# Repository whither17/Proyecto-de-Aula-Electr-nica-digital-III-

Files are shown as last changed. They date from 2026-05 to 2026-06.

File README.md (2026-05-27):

## Descripción detallada del proyecto final 
*Black Sisyphus*

Proyecto final del curso <br>
**Electrónica Digital III** 

Integrantes equipo Turing

**_Andres Felipe Agudelo Zapata_**<br>
**_Robinson Correa Morales_** 

---

## Descripción

El proyecto consiste en un robot autónomo capaz de:

- Navegar dentro de una región delimitada.
- Detectar cajas mediante sensores.
- Clasificar cajas negras y blancas.
- Expulsar únicamente las cajas negras del área de trabajo.
- Ignorar las cajas blancas.
- Generar un mapa virtual del entorno.
- Reexplorar el área periódicamente.

La arena de pruebas tiene dimensiones aproximadas de **100 cm x 70 cm** y está dividida en 4 cuadrantes mediante líneas negras de cinta aislante.

---

# Hardware utilizado

## Procesamiento
- Raspberry Pi Pico

## Sensores
- MPU-6050 (IMU)
- HC-SR04 (Ultrasónico)
- Sensores infrarrojos
- Encoders integrados en los motores N20

## Actuadores
- 2 Motores N20 con encoder
- Driver TB6612FNG

## Alimentación
- Batería Li-Po 7.4V
- Reductor MP1584

---

# Características

- Navegación autónoma
- Odometría y fusión sensorial
- Control PID
- Detección de límites
- Clasificación por color
- Mapeo periódico del entorno

---

# Arquitectura de software

El firmware utiliza una arquitectura basada en Polling + Interrupciones.

## Capas del sistema

### Drivers
Control e integración de hardware:
- TB6612FNG
- IMU
- Ultrasonido
- Encoders
- Sensores infrarrojos

### Estimación
- Odometría
- Fusión sensorial
- Estimación de posición
- Generación del mapa virtual

### Navegación y control
- Control PID
- Planeación de trayectorias
- Corrección de movimiento

### Aplicación
Implementa la lógica general del robot mediante una máquina de estados.

---

# Máquina de estados

| Estado | Función |
|---|---|
| APP_INIT | Inicialización |
| APP_EXPLORE | Exploración |
| APP_APPROACH_BOX | Aproximación a cajas |
| APP_IDENTIFY_BOX | Identificación del color |
| APP_PUSH_BOX | Expulsión de cajas negras |
| APP_CENTER | Retorno al centro |
| APP_WAIT | Espera para nuevo mapeo |

---

# Requisitos funcionales

- Navegación autónoma.
- Exploración sistemática.
- Detección de cajas.
- Clasificación por color.
- Expulsión de cajas negras.
- Ignorar cajas blancas.
- Retorno automático al centro.
- Reexploración periódica.

---

# Requisitos no funcionales

- Peso menor a 1 kg.
- Fácil transporte.
- Estructura resistente.
- Autonomía mínima de 15 minutos.
- Bajo consumo energético en espera.

---

# Pruebas

1. Detectar y expulsar una caja negra.
2. Detectar e ignorar una caja blanca.
3. Clasificar múltiples cajas negras y blancas.
4. Retornar al centro al finalizar.
5. Reiniciar el mapeo automáticamente.

---

# Estructura del proyecto

```text
├── Drivers
│   ├── Driver_TB6612FNG
│   ├── imu
│   ├── ultrasonic
│   ├── encoder
│   └── infrarrojo
│
├── Estimacion
│   └── estimacion.c/h
│
├── Navegacion
│   ├── control.c/h
│   └── navegacion.c/h
│
└── Aplicacion
    └── aplicacion.c/h

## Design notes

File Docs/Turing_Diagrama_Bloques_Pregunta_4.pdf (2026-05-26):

ROBINSON CORREA MORALES | AVANCE DEL PROYECTO FINAL
ANDRES FELIPE AGUDELO ZAPATA | 23/05/2026
ELECTRÓNICA DIGITAL III

### Diagrama de Bloques

La alimentación del circuito es mediante una batería Li-Po con voltaje nominal de 7.4 V que después cae a un reductor de voltaje MP1584 que la reduce a 5 V. Con este voltaje se alimentan tanto el pin VSYS de la Raspberry Pi pico como el sensor de ultrasonido. Por su parte, el pin de VM del puente H TB6612FNG es alimentado con los 7.4 V suministrados por la batería.

Para el puente H además de la conexión de los 7.4 V con su respectiva tierra se conectan los pines de VCC, STDBY a el pin de 3.3 V y se pone la tierra común del pin de la Raspberry, además los pines de AI1, AI2, PWMA, BI1, BI2, PWMB se conectan a los GPIOS de la Raspberry mientras que los pines de A01, A02, B01, BO2 se conectan a los cables rojos y blancos de los dos motores N20.

Para hacer uso de los encoders acoplados a los motores alimentamos los cables negros a 3.3 V y los azules a GND y las salidas de los dos canales cable amarillo y verde van a 2 pines GPIOs.

Ambos sensores infrarrojos se alimentan a 3.3 V que los proporciona la Raspberry y sus salidas se leen en GPIOs.

La IMU también se alimentan a 3.3V y se conectan los pines SDA y SCL a dos pines de la Raspberry que soporten comunicación I2C.

El ultrasonido es el único sensor que no se debe alimentar a 3.3V, ya que trabaja a 5 V, para proteger la Raspberry, salida de este sensor(el pin Echo) debe pasar por un divisor de tensión con resistencias de 4.7k y de 10k. La entrada (Trig) puede funcionar con una entrada de 3.3 V por lo que no requiere acondicionamiento.

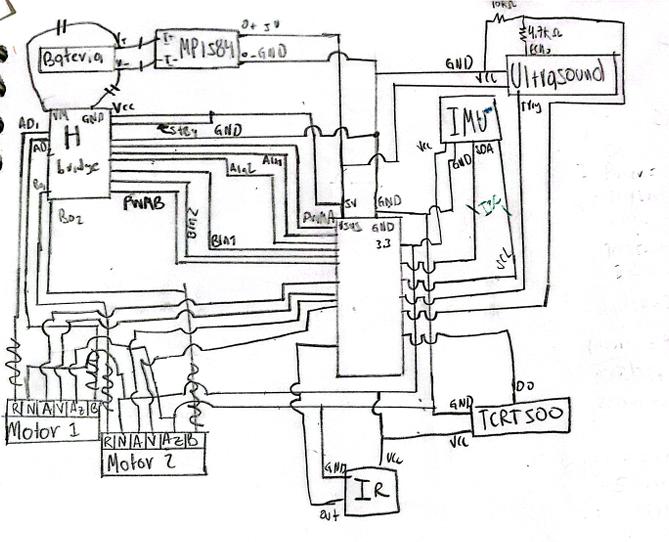
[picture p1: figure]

ROBINSON CORREA MORALES | AVANCE DEL PROYECTO FINAL
ANDRES FELIPE AGUDELO ZAPATA | 23/05/2026
ELECTRÓNICA DIGITAL III

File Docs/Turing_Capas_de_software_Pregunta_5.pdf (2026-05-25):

ROBINSON CORREA MORALES | AVANCE DEL PROYECTO FINAL
ANDRES FELIPE AGUDELO ZAPATA | 23/05/2026
ELECTRÓNICA DIGITAL III

### Respuesta a la pregunta 5

Arquitectura de software
El firmware del sistema estará organizado mediante una arquitectura de Polling más interrupciones. Las interrupciones se utilizan en puntos críticos donde se requiere minimizar el error. Dado que el robot debe navegar por si mismo, saber dónde está y corregir su movimiento, evitar que el error se acumule es crucial. El software está conformado por las siguientes capas:
- Drivers
- Estimación
- Navegación y control
- Aplicación

Drivers
Esta capa se encarga de configurar e inicializar los diferentes sensores y sistemas del vehículo y ofrecer una integración transparente entre el hardware y el resto del software. Aquí se incluyen los drivers de ambos motores, el driver de la unidad de medición inercial, el driver del sensor ultrasónico, driver del encoder de los motores y el driver de los sensores infrarrojos detectores de línea. La capa Drivers está conformada por los siguientes módulos:
- | Driver_TB6612FNG: | Conformado | por | los | archivos | Driver_TB6612FNG. | c /
Driver_TB6612FNG.h | , implementa las funciones que permiten realizar las siguientes tareas:
- Implementar las funciones de control de velocidad.
- Dirección del giro del motor.
- Generación del PWM necesario para controlar la velocidad.
| • Frenar el motor.
- | IMU: Conformado por los archivos imu.c / imu.h | , implementa las funciones que permiten
configurar, inicializar y utilizar la unidad de medición inercial (IMU). Las tareas de este módulo
| son:
- Inicializar la comunicación I2C
- Configurar los registros internos del MPU-6050.
- Realizar calibración.
- Leer los datos crudos medidos por el acelerómetro y giroscopio.
- Establecer los rangos de las mediciones.
- Procesar las mediciones y transformarlas en unidades físicas utilizables por el sistema.
- | Ultrasonic: Conformado por los archivos ultrasonic | .c / | ultrasonic | .h , implementa
las funciones que permiten utilizar el sensor ultrasónico HC-SR04. Sus tareas son:
- Gestionar la temporización del sensor ultrasónico.
- Generar los pulsos de disparo del sensor.
- Medir la duración del eco.
- Estimar de la distancia.

ELECTRÓNICA DIGITAL III

Este módulo emplea interrupciones de temporizador (TIMER_IRQ) para medir con precisión la duración de los pulsos y estimar correctamente la distancia.

- | Encoder: Conformado por los archivos encoder.c /encoder.h | , se encarga de determinar
las revoluciones y el recorrido de cada rueda. Sus tareas son:
- Contar los pulsos por medio de las interrupciones GPIO
- Implementar una temporización periódica para el cálculo de velocidad angular.
- Estimar las RPM del motor.
- Estimar el desplazamiento del robot.
- Filtrar las lecturas de ser necesario.
- | Infrarrojo: Conformada por los archivos infrarrojo.c / infrarrojo.h | , permite
ejecutar las tareas relacionadas con la lectura de los cuadrantes del área de trabajo y el límite de esta además de identificar el color de la caja. Dado que el robot posee dos sensores infrarrojos con tareas distintas, se aclara que cada sensor tiene sus funcionalidades específicas:
- Sensor inferior: Detectar los límites del área de trabajo.
- Sensor frontal: Determinar el color de la caja cuando el robot se acerque a ella.

La información de estos sensores les indica a las capas superiores información relevante para la corrección del mapa del entorno.

Estimación
Esta capa se encarga de realizar la odometría y la fusión sensorial. Se comunica con la capa de drivers, de donde obtiene los datos necesarios para saber en donde se encuentra el robot. Esta capa le da la capacidad al robot de responder a las preguntas ¿Dónde estoy? ¿Qué hay en el entorno? ¿Cómo me estoy moviendo? Por medio de la integración de las distintas métricas. Esta capa es un único módulo formado por los archivos
estimaci | on.c / estimaci | on.h , Las funciones del módulo son las siguientes:
- Realizar la odometría del robot
- Obtener los datos de la unidad de medición inercial.
- Fusionar los datos de la IMU con la odometría reduciendo el efecto de deriva.
- Detectar las cajas por medio de la lectura del sensor ultrasónico.
- Determinar el color de la caja.
- Estimar la posición del robot en el área de trabajo tanto en (x, y) como angularmente.
- Estimar la velocidad del robot.
- Determinar la distancia a la caja.
- Generar el mapa virtual del entorno.

Navegación y control
Esta capa se encarga de controlar el movimiento del robot y planificar su trayectoria por medio de distintas métricas proporcionadas por la capa de Estimación. Esta capa la conforman dos módulos control.c /.h y navegaci on.c/.h
- Control: Sus funciones son:
- Realizar el control de bajo nivel de la velocidad y dirección del motor.
- Implementar el control PID de los motores.

ELECTRÓNICA DIGITAL III

- Corregir las desviaciones en la trayectoria.
- Navegación: Sus funciones son:
- Calcular la ruta hacia las cajas detectadas.
- Ignorar las cajas que ya han sido identificadas por su color.
- Coordinar las maniobras de aproximación y empuje.
- Detectar la salida del área de trabajo y corregir la ruta para reingresar a él.
- Generar referencias de orientación y velocidad para el robot.

Aplicación
Esta capa integra la aplicación del robot. Define el comportamiento específico a nivel de usuario, dictando que hace y que no hace el robot. El robot busca cajas dentro de su entorno de trabajo y extrae de él las cajas de color negro e ignora las cajas de otro color. Cuando detecta a distancia una caja, si no la ha identificado antes, se acerca a ella y la identifica. Si la caja identificada es negra, la expulsa fuera del área de trabajo. Una vez no hallan más cajas negras, el robot se situará en el centro del área de trabajo y volverá
a leer el entorno pasados 4 minutos. Está conformada por el módulo aplicación.c/.h | , cuyas funciones
son:
- Tomar las decisiones de alto nivel por medio de la máquina de estados general del robot.
- Coordinar las capas inferiores.
- Implementar el comportamiento general del robot cumpliendo así con los requisitos funcionales propuestos.

La Máquina de estados tiene por estados:

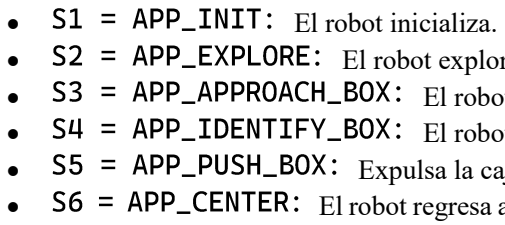
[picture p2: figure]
APP_INIT : El robot inicializa.

- | S2 = | APP_EXPLORE : El robot explora su entorno y crea un mapa virtual de él.
- | S3 = | APP_APPROACH_BOX : El robot busca cajas en la distancia y las detecta.
- | S4 = | APP_IDENTIFY_BOX | : El robot identifica la caja que tiene en frente.
- | S5 = | APP_PUSH_BOX : Expulsa la caja identificada si es de color negro.
- S6 = APP_CENTER : El robot regresa al centro del área de trabajo cuando ya no queden cajas
| negras.
- | S7 = | APP_WAI T: El robot espera durante un tiempo definido para volver a explorar.

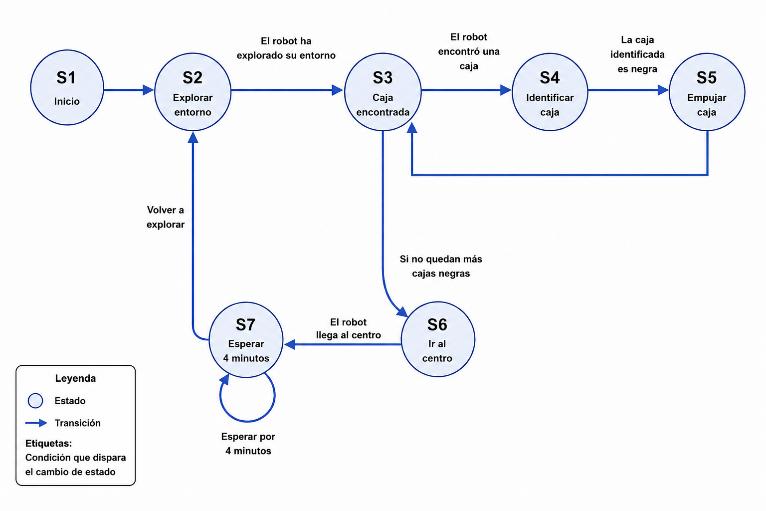
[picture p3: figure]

Esquema de la máquina de estados finitos de la aplicación.

ELECTRÓNICA DIGITAL III

Dado que el sistema posee una arquitectura basada en Polling + Interrupciones, las interrupciones son empleadas en aquellos puntos críticos donde se requiere reacción rápida por parte del sistema. Las interrupciones más importantes utilizadas son:

Interrupciones GPIO
Empleadas por los encoders de los motores, se utilizan para detectar los flancos de pulso. Cada interrupción incrementa o decrementa el conteo de los pulsos necesarios para la odometría. También es utilizado por el driver del sensor infrarrojo.

Interrupciones de TIMING
Empleadas principalmente por el sensor ultrasónico para medir correctamente la distancia y por el módulo Driver_TB6612FNG para realizar el envío periódico de la velocidad y dirección. También se utilizarán interrupciones de timing e interrupciones periódicas en secciones de la lógica que requieran manejo del tiempo.

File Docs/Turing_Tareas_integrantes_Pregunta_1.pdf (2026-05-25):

ROBINSON CORREA MORALES | AVANCE DEL PROYECTO FINAL
ANDRES FELIPE AGUDELO ZAPATA | 23/05/2026
ELECTRÓNICA DIGITAL III

### Tareas integrantes

Andres Agudelo:

- Montaje del chasis. (80%):
Búsqueda del diseño 3D del carro su acople y verificación de su correcto funcionamiento
- Diseño de la PCB. (100%)
Diseño del shield de la raspberry pi pico con acondicionamiento de señales en los GPIOS que lo requieran.
- Compra de materiales. (99%)
- Testeo de componentes. (60%)
Verificación de que todos los componentes comprados funcionen adecuadamente y estén listos para su uso en el proyecto.
- Desarrollo de la odometria. (10%)
Desarrollo de la odometria del carro por medio de los enconders, el uso de la IMU y la corrección de errores acumulativos por medio de las líneas en los bordes y la cruz central que divide la arena en 4 cuadrantes.
- Desarrollo del mapa de obstáculos en la memoria. (0%)
En base a la posición del carro su orientación y la información que brinde el sensor de ultrasonido definir un mapa de obstáculos.
- Desarrollo del control del carro. (0%)
Desarrollo del movimiento de mapeo de la región del carro evitando los obstáculos que se encuentren en la región.
- Desarrollo de la arquitectura de Hardware. (100%)

Robinson Correa:

- Impresión PCB. (100%)
- Desarrollo de comunicación I2C necesaria para el uso de la IMU. (50%)
Para utilizar adecuadamente la IMU es necesario el desarrollo de un protocolo de comunicación I2C para la adquisición de los parámetros del giroscopio y del acelerómetro.
- Desarrollo de la función de empuje de obstáculos. (0%)
Una vez el carro detecte un obstáculo negro el carro deberá de sacarlo de la región de trabajo.
- Desarrollo de la región de pruebas. (100%)
En un pliego de cartulina se desarrolló una región de pruebas con cinta negra en los bordes y una cruz en el centro con cinta negra que divide la región de pruebas en 4 cuadrantes.
- Testeo de la odometria y navegación del carro. (0%)
Realizar varias pruebas en las que se verifique si el carro si logra detectar su posición espacial en cada tiempo y sabe cómo llegar a puntos ya conocidos previamente sin caer en errores.
- Desarrollo del control del carro. (0%)
Mediante revisión de parámetros de control lograr que el carro llegue a las posiciones necesarias sin oscilaciones y en un tiempo adecuado.
- Desarrollo de la arquitectura de Software. (100%)

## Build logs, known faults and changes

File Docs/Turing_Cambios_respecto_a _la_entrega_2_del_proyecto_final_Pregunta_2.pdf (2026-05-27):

ROBINSON CORREA MORALES | Corrección a la entrega número 2
ANDRES FELIPE AGUDELO ZAPATA | 23/05/2026
ELECTRÓNICA DIGITAL III

### Cambios respecto a la entrega 2 del proyecto final

Para el proyecto final se desarrollará un vehículo autónomo, que navegara en una región del tamaño de un pliego de cartulina blanca (100cm x 70cm), dentro de esta región se encontraran dos tipos de cajas unas de color negro y otras de color blanco, el trabajo del robot será sacar las cajas negras de la región, e ignorar las cajas blancas. Una vez no haya más cajas negras en la región el robot volverá al centro y hará nuevos mapeos de la región de manera periódica cada 4 minutos.

El robot se mueve mediante el uso de dos motores N20 (antes: Tracción 4 x 4) que se encuentran en dos esquinas contrarias del chasis, este robot se desplazara mediante el uso de orugas.

Para determinar su posición en el espacio el robot recibe información del mundo exterior mediante 3 sensores, los enconder de cada motor que le dicen cuántas vueltas a dado cada motor, una IMU que nos dará información sobre giros y la orientación del carro y un sensor de línea que detectara las líneas que se encuentran en los bordes de la región y en una cruz que divide la región en 4 cuadrantes iguales (antes: No quedó clara la función del sensor seguidor de línea y las marcas con cinta negra) esta medida la hacemos para actualizar la información de la ubicación del carro con medidas ya conocidas que nos permitirá reducir el error acumulativo que tendría la odometría en caso de no realizarse.

Los principales cambios respecto a la entrega anterior es que se cambió el objetivo de llevar las cajas al centro a simplemente sacarlas del área de trabajo, lo que elimina el estado de espera en la que el carro esperaba que le quitaran la caja del centro, en vez de eso se desarrolló un mapeo periódico de 4 minutos en la que el carro recorrerá de nuevo la región. Las cajas también se han cambiado de un cubo de 4 cm de lado a un cubo de 7 cm de lado, pero mantienen la naturaleza de ser blancas o negras.

También se amplió la región de trabajo de una de 60cm x 60cm a una de 100cm x 70cm de cartulina blanca con bordes y división en 4 cuadrantes señalizados con cinta negra (antes: se daba a entender que era en la cerámica del suelo), lo que tiene más sentido con las dimensiones del automóvil, y se cambió el hecho de que el carro siga una tracción 4x4 por una de orugas como la de un tanque. En base a los cambios las nuevas pruebas serán:

- Prueba 1: Se colocará una sola caja negra en la arena se verificará que el robot la encuentre y la clasifique como negra, para después sacarla de la arena.
- Prueba 2: Se colocará una sola caja blanca se verificará que el robot la encuentre la clasifique como blanca y siga su escaneo de la región ignorando esta caja identificada.
- Prueba 3: Se colocarán 2 cajas negras y 2 blancas en la región de trabajo garantizando que ninguna caja impida el acceso a las demás cajas ni su correcta eliminación hacia uno de los costados la prueba será exitosa cuando en la arena solo queden las 2 cajas blancas.
- Prueba 4: Cuando no haya más cajas negras en el campo de trabajo se verificará que el robot retorne a la región central.

ELECTRÓNICA DIGITAL III

- Prueba 5: Pasados una cantidad de tiempo N el cual por cuestiones de velocidad tomará un valor de un minuto después de que el carro haya retornado a la región central el carro deberá de volver a iniciar un mapeo de la región.

Requisitos funcionales:

- RF1 Navegación automática por odometría y fusión de sensores: el vehículo deberá estimar su posición y orientación en todo momento de su ejecución utilizando los encoders de cada motor, la unidad de medición inercial, el sensor ultrasónico y los sensores infrarrojos seguidores de línea .
- RF2 El vehículo deberá de moverse en la región de trabajo (antes: 60 x 60 cm) de manera sistemática para encontrar todas las cajas en la región.
- RF3 El vehículo deberá de detectar la presencia y ubicación de las cajas por medio de un sensor ultrasónico.
- RF4 Al aproximarse a una caja detectada el robot deberá determinar su color por medio de un sensor de línea infrarrojo.
- RF5 El vehículo deberá de empujar las cajas detectadas como negras fuera de la región de trabajo (antes: Hacia el centro del área de trabajo).
- RF6 Las cajas blancas deberán de ser ignoradas por el robot. Una caja identificada como blanca no deberá ser movida por el robot .
- RF7 El sistema deberá de almacenar internamente las posiciones estimadas de todas las cajas detectadas durante su barrido de la región.
- Requisito eliminado: Una vez se haya llevado una caja al centro de la región el vehículo deberá detenerse y permanecer en espera hasta que esta se retire.
- Requisito eliminado: El vehículo deberá de ser capaz de detectar cuando la caja del centro ha sido retirada.
- RF8 Cuando no haya más cajas negras el robot debe de volver al centro y esperar el tiempo definido para luego volver a mapear su entorno.
- RF9 El robot no deberá salirse del área de pruebas. En caso de que ocurra, deberá reingresar a ella, si no puede, deberá detenerse.

Requisitos NO funcionales:

- Eliminado: El vehículo tendrá tracción 4 x 4 y el cambio de dirección se realizará cambiando la velocidad y sentido cada rueda.
- RNF1 El vehículo será ligero, no superará el kilogramo de peso y será fácil de transportar.
- RNF2 El vehículo estará bien ensamblado, evitando que se rompa al transportarlo o manipularlo.
- RNF3 Las baterías han de garantizar el funcionamiento en todas las pruebas ejecutadas o una demostración de funcionamiento superior a los 15 minutos.

ELECTRÓNICA DIGITAL III

- RNF4 El robot reducirá su consumo energético durante el tiempo de espera tras finalizada una ronda.

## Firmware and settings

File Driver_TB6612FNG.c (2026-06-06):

#include "Driver_TB6612FNG.h"

/* ─────────────────────────────────────────────────────────────────────────────
   DEFINICIÓN DE PINES Y CONSTANTES
   ───────────────────────────────────────────────────────────────────────────── */

/* Motor izquierdo — canal A */
#define PIN_AIN1   20  /* GP20 — dirección izquierdo bit-0 */
#define PIN_AIN2   21  /* GP21 — dirección izquierdo bit-1 */
#define PIN_PWMA   12  /* GP12 — PWM slice 6, canal A      */

/* Motor derecho — canal B */
#define PIN_BIN1   19  /* GP19 — dirección derecho bit-0   */
#define PIN_BIN2   18  /* GP18 — dirección derecho bit-1   */
#define PIN_PWMB   13  /* GP13 — PWM slice 6, canal B     */

/* CONSTANTES */
#define MAXPWM 70 /* Los motores solo reciben hasta 6v la alimentacion es de 7.4v con valores de hasta 8.4v usamos un 70% como segurridad*/
#define PWM_WRAP 12499 /* Para una frecuencia de 10 KHz con reloj del micro de 125 MHz*/
#define PWMSlice 6 /* El canal de PWM a usar es el 6 ya que este es el del GPIO 12(A) y del GPIO 13(B) */

/* ─────────────────────────────────────────────────────────────────────────────
   Variables Internas
   ───────────────────────────────────────────────────────────────────────────── */

/* Ciclos de dureza a aplicar en los motores en la proxima IRQ */
static volatile uint16_t g_duty_left  = 0;
static volatile uint16_t g_duty_right = 0;

/* Banderea de cambio de estado */
static volatile bool g_cmd_pending = false;

/* Base de tiempo por medio del uso de las interrupciones */
static volatile uint32_t g_pwm_ticks = 0;


/* Handler de la interrupcion*/
static void pwm_wrap_isr(void) {
    /* Limpiamos la Flag */
    pwm_clear_irq(PWMSlice);
    g_pwm_ticks++;

    /* Aplicar nuevo duty cycle si hay un comando pendiente */
    if (g_cmd_pending) {
        uint16_t limit =((uint16_t)((MAXPWM * (int)PWM_WRAP) / 100));
        if (g_duty_left > limit)
        {
            pwm_set_chan_level(PWMSlice,  PWM_CHAN_A, limit);
        }else{
            pwm_set_chan_level(PWMSlice,  PWM_CHAN_A, g_duty_left);
        }
        if (g_duty_right > limit)
        {
            pwm_set_chan_level(PWMSlice,  PWM_CHAN_B, limit);
        }else{
            pwm_set_chan_level(PWMSlice,  PWM_CHAN_B, g_duty_right);
        }
        g_cmd_pending = false;
    }
}

/**
 * set_motor_direction_left()
 * Configura AIN1/AIN2 según el signo de speed.
 *
 *   speed > 0  →  AIN1=1, AIN2=0  (adelante)
 *   speed < 0  →  AIN1=0, AIN2=1  (atrás)
 *   speed = 0  →  AIN1=0, AIN2=0  (freno)
 */
static inline void set_motor_direction_left(int speed) {
    if (speed > 0) {
        gpio_put(PIN_AIN1, 1);
        gpio_put(PIN_AIN2, 0);
    } else if (speed < 0) {
        gpio_put(PIN_AIN1, 0);
        gpio_put(PIN_AIN2, 1);
    } else {
        gpio_put(PIN_AIN1, 0);
        gpio_put(PIN_AIN2, 0);
    }
}

/**
 * set_motor_direction_right()
  * Configura BIN1/BIN2 según el signo de speed.
 *
 *   speed > 0  →  BIN1=1, BIN2=0  (adelante)
 *   speed < 0  →  BIN1=0, BIN2=1  (atrás)
 *   speed = 0  →  BIN1=0, BIN2=0  (freno)
 */
static inline void set_motor_direction_right(int speed) {
    if (speed > 0) {
        gpio_put(PIN_BIN1, 1);
        gpio_put(PIN_BIN2, 0);
    } else if (speed < 0) {
        gpio_put(PIN_BIN1, 0);
        gpio_put(PIN_BIN2, 1);
    } else {
        gpio_put(PIN_BIN1, 0);
        gpio_put(PIN_BIN2, 0);
    }
}

/**
 * speed_to_duty()
 * Convierte porcentaje [-100, 100] a valor de wrap [0, PWM_WRAP].
 * La dirección va por los pines IN, no por el duty — siempre positivo.
 */
static inline uint16_t speed_to_duty(int speed) {
    if (speed >  100) speed =  100;
    if (speed < -100) speed = -100;
    return (uint16_t)((abs(speed) * (int)PWM_WRAP) / 100);
}

/**
 * motors_set()
 * pasamos de un valor de velocidad cruda a la organizacion de los diferentes pines
 * y el ciclo de dureza de los canales PWM
 */
 void motors_set(int left_speed, int right_speed) {
    set_motor_direction_left(left_speed);
    set_motor_direction_right(right_speed);

    g_duty_left  = speed_to_duty(left_speed);
    g_duty_right = speed_to_duty(right_speed);
    g_cmd_pending = true;
}

void motor_driver_init(void) {

    /* ── 7.1  GPIO de dirección y STBY ── */
    const uint dir_pins[] = {PIN_AIN1, PIN_AIN2, PIN_BIN1, PIN_BIN2};
    for (int i = 0; i < 4; i++) {
        gpio_init(dir_pins[i]);
        gpio_set_dir(dir_pins[i], GPIO_OUT);
        gpio_put(dir_pins[i], 0);
    }

    /* ── 7.2  Función PWM en los pines de potencia ── */
    gpio_set_function(PIN_PWMA, GPIO_FUNC_PWM);   /* GP12 → slice 6  ch-A */
    gpio_set_function(PIN_PWMB, GPIO_FUNC_PWM);   /* GP21 → slice 10 ch-B */

    /* ── 7.3  Configuración de los dos slices con parámetros idénticos ── */
    pwm_config cfg = pwm_get_default_config();
    pwm_config_set_clkdiv_int(&cfg, 1);
    pwm_config_set_wrap(&cfg, PWM_WRAP);

    /* Slice 6  — motor izquierdo (GP12, canal A) */
    pwm_init(PWMSlice,  &cfg, false);
    pwm_set_chan_level(PWMSlice,  PWM_CHAN_A, 0);
    pwm_set_chan_level(PWMSlice, PWM_CHAN_B, 0);

    /* ── 7.4  Interrupción PWM ── */

    /*
     *  Habilitar la IRQ de wrap en AMBOS slices.
     *  El RP2040 tiene una única línea PWM_IRQ_WRAP — la misma ISR
     *  recibe la interrupción de cualquiera de los dos slices.
     *  Por eso la ISR limpia los flags de los dos.
     */
    pwm_clear_irq(PWMSlice);
    pwm_set_irq_enabled(PWMSlice,  true);

    /* Registrar el handler y configurar prioridad */
    irq_set_exclusive_handler(PWM_IRQ_WRAP, pwm_wrap_isr);
    irq_set_priority(PWM_IRQ_WRAP, 0u);   /* 0 = máxima en Cortex-M0+ */
    irq_set_enabled(PWM_IRQ_WRAP, true);

    /* ── 7.5  Arranque ── */

    /* Activar ambos slices simultáneamente para minimizar desfase inicial */
    pwm_set_enabled(PWMSlice,1);
}
uint32_t motor_get_ticks(void) {
    irq_set_enabled(PWM_IRQ_WRAP, false);
    uint32_t t = g_pwm_ticks;
    irq_set_enabled(PWM_IRQ_WRAP, true);
    return t;
}

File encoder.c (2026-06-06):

/**
 * =============================================================================
 *  encoder.c
 *  Robot autónomo de mapeo — Módulo 2: Encoders de cuadratura
 * =============================================================================
 *
 *  Plataforma : Raspberry Pi Pico (RP2040)
 *  Lenguaje   : C puro (sin SO, bare-metal)
 *  Encoders   : Magnéticos de cuadratura, 2 canales (A y B) por rueda
 *
 *  ── Pinout ───────────────────────────────────────────────────────────────────
 *
 *  Rueda izquierda
 *    Canal A → GP0   (dispara la IRQ en flanco de subida y bajada)
 *    Canal B → GP1   (se lee dentro del handler para detectar dirección)
 *
 *  Rueda derecha
 *    Canal A → GP17  (dispara la IRQ en flanco de subida y bajada)
 *    Canal B → GP16  (se lee dentro del handler para detectar dirección)
 *
 *  ── Cómo funciona la detección de dirección ──────────────────────────────────
 *
 *  En un encoder de cuadratura los canales A y B están desfasados 90°.
 *  Cuando el motor gira hacia adelante, A sube ANTES que B:
 *
 *    Adelante:   A sube → B está en ALTO   → tick positivo
 *    Atrás:      A sube → B está en BAJO   → tick negativo
 *
 *  Disparando en ambos flancos (subida Y bajada) de A se duplica la
 *  resolución del encoder sin necesidad de leer el canal B dos veces.
 *
 *    Flanco de SUBIDA  de A + B en ALTO  → avanza  → ticks++
 *    Flanco de SUBIDA  de A + B en BAJO  → retrocede → ticks--
 *    Flanco de BAJADA  de A + B en BAJO  → avanza  → ticks++
 *    Flanco de BAJADA  de A + B en ALTO  → retrocede → ticks--
 *
 *  ── Arquitectura de interrupciones ──────────────────────────────────────────
 *
 *  El RP2040 tiene un único callback GPIO (IO_IRQ_BANK0).
 *  Este driver NO registra el callback — eso lo hace el main.
 *  Este driver solo:
 *    1. Configura los pines como entradas con pull-up.
 *    2. Habilita la IRQ en los pines A de ambos encoders.
 *    3. Expone encoder_handle_irq() para que el main la llame
 *       desde su gpio_irq_handler cuando corresponda.
 *
 *  ── Base para odometría ──────────────────────────────────────────────────────
 *
 *  Este módulo solo cuenta ticks. La conversión a distancia y ángulo
 *  se hace en la capa superior de odometría con:
 *
 *    distancia = ticks * (PI * diametro_rueda / pulsos_por_vuelta)
 *
 *  Los parámetros físicos (diámetro, pulsos por vuelta) no viven aquí
 *  sino en el módulo de odometría, ya que son propiedades del robot,
 *  no del sensor.
 *
 * =============================================================================
 */

#include "encoder.h"

/* ─────────────────────────────────────────────────────────────────────────────
   ESTADO INTERNO
   ───────────────────────────────────────────────────────────────────────────── */

/* Contadores de pulsos — volatile porque se modifican en la ISR */
static volatile int32_t ticks_left  = 0;
static volatile int32_t ticks_right = 0;

/* ─────────────────────────────────────────────────────────────────────────────
   INICIALIZACIÓN
   ───────────────────────────────────────────────────────────────────────────── */

void encoder_init(void) {

    /* Configurar los cuatro pines como entradas con pull-up interno.
       Pull-up porque los encoders magnéticos suelen tener salida de
       colector abierto — sin pull-up el pin flota y genera IRQ falsas. */
    uint8_t pins[] = {
        ENCODER_LEFT_A, ENCODER_LEFT_B,
        ENCODER_RIGHT_A, ENCODER_RIGHT_B
    };
    for (int i = 0; i < 4; i++) {
        gpio_init(pins[i]);
        gpio_set_dir(pins[i], GPIO_IN);
        gpio_pull_up(pins[i]);
    }

    /*
     *  Habilitar IRQ en los canales A — flancos de SUBIDA y BAJADA.
     *  Disparar en ambos flancos duplica la resolución:
     *  por cada ciclo completo del encoder se obtienen 4 eventos
     *  en vez de 2, mejorando la precisión de la odometría.
     *
     *  IMPORTANTE: NO se registra el callback aquí.
     *  El main llama gpio_set_irq_enabled_with_callback() una sola vez
     *  con su gpio_irq_handler general. Este driver solo habilita
     *  los pines para que generen la interrupción.
     */
    gpio_set_irq_enabled(ENCODER_LEFT_A,
        GPIO_IRQ_EDGE_RISE | GPIO_IRQ_EDGE_FALL, true);

    gpio_set_irq_enabled(ENCODER_RIGHT_A,
        GPIO_IRQ_EDGE_RISE | GPIO_IRQ_EDGE_FALL, true);
}

/* ─────────────────────────────────────────────────────────────────────────────
   HANDLER — llamado desde el gpio_irq_handler del main
   ───────────────────────────────────────────────────────────────────────────── */

/**
 * encoder_handle_irq()
 *
 * El main la llama desde su gpio_irq_handler pasando el pin que disparó
 * y el tipo de evento. Esta función decide si el evento corresponde a
 * un encoder, en qué dirección giró y actualiza el contador.
 *
 * Lógica de cuadratura:
 *   Flanco RISE en A + B en ALTO  → adelante  → ++
 *   Flanco RISE en A + B en BAJO  → atrás     → --
 *   Flanco FALL en A + B en BAJO  → adelante  → ++
 *   Flanco FALL en A + B en ALTO  → atrás     → --
 *
 * En resumen: tick positivo cuando A y B están en el mismo estado,
 * tick negativo cuando están en estados opuestos.
 */
void encoder_handle_irq(uint gpio, uint32_t events) {

    if (gpio == ENCODER_LEFT_A) {
        bool a_rise = (events & GPIO_IRQ_EDGE_RISE) != 0;
        bool b_high = gpio_get(ENCODER_LEFT_B);

        /* Mismo estado → adelante, estado opuesto → atrás */
        if (a_rise == b_high) {
            ticks_left++;
        } else {
            ticks_left--;
        }
    }
    else if (gpio == ENCODER_RIGHT_A) {
        bool a_rise = (events & GPIO_IRQ_EDGE_RISE) != 0;
        bool b_high = gpio_get(ENCODER_RIGHT_B);

        /*
         *  El motor derecho está montado en espejo respecto al izquierdo.
         *  Si al probar el robot los ticks del derecho cuentan al revés,
         *  invierte esta lógica cambiando == por !=
         */
        if (a_rise == b_high) {
            ticks_right++;
        } else {
            ticks_right--;
        }
    }
}

/* ─────────────────────────────────────────────────────────────────────────────
   LECTURA ATÓMICA — para la capa de odometría
   ───────────────────────────────────────────────────────────────────────────── */

/**
 * encoder_get_left()
 * encoder_get_right()
 *
 * Deshabilitan brevemente la IRQ de GPIO para garantizar que el valor
 * de 32 bits se lee completo sin que una interrupción lo modifique
 * a la mitad. En Cortex-M0+ las lecturas de 32 bits no son atómicas
 * si pueden ser interrumpidas entre los dos accesos de 16 bits internos.
 */
int32_t encoder_get_left(void) {
    irq_set_enabled(IO_IRQ_BANK0, false);
    int32_t t = ticks_left;
    irq_set_enabled(IO_IRQ_BANK0, true);
    return t;
}

int32_t encoder_get_right(void) {
    irq_set_enabled(IO_IRQ_BANK0, false);
    int32_t t = ticks_right;
    irq_set_enabled(IO_IRQ_BANK0, true);
    return t;
}
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

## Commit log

2026-05-24 Agregar diseño de la PCB
    [PCB_Final.brd]
2026-05-25 Driver puente H TB6612FNG controlado por IRQ
2026-05-25 Agregar documentación relacionada con el avance
2026-05-27 Corrección de las medias del área
2026-05-27 Desarollo del driver del encoder con cuenta tikcs
    Un tick es cuand uno de los dos canales A cambia de estado
